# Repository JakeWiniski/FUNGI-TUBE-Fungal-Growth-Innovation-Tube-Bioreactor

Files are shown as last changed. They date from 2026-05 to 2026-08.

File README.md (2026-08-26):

# FUNGI-TUBE: Fungal-Growth-Innovation-Tube-Bioreactor


FUNGI-TUBE (Fungal Growth & Innovation Tube Bioreactor) is a modular solid-state bioreactor system that integrates passive aeration and low-cost, non-invasive sensing to monitor and optimize fungal growth and metabolism across diverse applications—including mycelium materials, mushroom cultivation, and solid-state fermentation. Designed to maximize data richness relative to unit cost, the system supports large experimental arrays (high n) with a deep feature space, enabling time-resolved insight into both physical growth and metabolic activity. By coupling structural, optical, thermal, and gas-phase monitoring, FUNGI-TUBE functions as a low-cost “budget biofoundry” for adaptive learning, trait screening, and myco-centric R&D.

## FRAME — *Fungal-Response-And-Mycelium-Evolution Module*

The **FRAME** is the core unit of the system: a 50 mL conical centrifuge tube holder modified to support **non-invasive monitoring** of growth dynamics in solid-state fermentation. This sensorized tube holder houses the fungal culture in a standard conical 50mL centrifuge tube and enables quantitative tracking of growth development over time.

Each **FRAME** module integrates:

- **Capacitance sensor**  
  Detects changes in the dielectric properties of the solid substrate, providing a proxy signal for **mycelial growth, substrate colonization, and moisture dynamics**. The capacitance sensor in the FUNGI-TUBE system provides a non-invasive, quantitative proxy for fungal growth by detecting changes in the electrical properties of the substrate. As fungal mycelium colonizes the substrate, it alters the local dielectric environment through the accumulation of biomass, extracellular matrix, and moisture redistribution. These biological and physical changes effect the overall capacitance measured by the sensor, which is positioned externally along the substrate tube. This method allows for continuous, non-invasive, and low-cost tracking of mycelial expansion. Capacitance data, when analyzed alongside other sensor outputs such as CO₂, VOCs, and temperature, offers a powerful window into both structural growth dynamics and underlying metabolic activity.

- **RGB color sensor**  
  Measures the **relative brightness, pigmentation, and density** of surface mycelium. Useful for monitoring visual colonization density, morphological transitions, and the onset of **secondary metabolite** production (e.g., pigments).

- **Temperature sensor**  
  Logs **tube surface temperature**, enabling detection of **metabolic heat generation** and aiding in the interpretation of growth phase and respiration kinetics. Additional integrated external sensors also capture environment temperature. 

These sensors are mounted externally and aligned with the body of the tube, enabling continuous data acquisition without disturbing the culture. Sensor data is logged locally (or can be transmitted via ESP-NOW), supporting high-resolution time series analysis of fungal growth evolution.

When paired with the **FOGM** (Fungal Off-Gas Monitor) module, the FUNGI-TUBE system offers a low-cost, modular platform for studying fungal physiology, growth kinetics, and environmental response in real time.

## FOGM — *Fungal Off-Gas Monitor Module*

**FOGM** is a modular sensor chamber designed to monitor the gaseous byproducts of fungal growth in small-scale, solid-state fermentation systems — specifically the 50 mL **FUNGI-TUBE** bioreactor platform.

This detachable cap integrates multiple environmental sensors to passively sample the headspace gas diffusing from the growth tube, providing real-time data on:

- **CO₂ concentration** 
- **Relative humidity (RH)**  
- **Volatile organic compounds (VOCs)**  

The FOGM chamber features a tortuous internal gas path with inlet and outlet ports that encourage mixing, prevent direct gas escape, and stabilize readings. It is designed to be 3D printable and easy to assemble.

FOGM enables detailed monitoring of fungal metabolic activity and environmental response in micro-cultivation experiments. Paired with the FRAME this allows for hollistic co-featurization of mycelium and metabolic evolution. 

## FUNGI-TUBE Shield & Firmware

The FUNGI-TUBE Shield is a purpose-built expansion board designed to support operation with the ESP32 microcontroller, providing both the core functionality and flexible optionality needed for diverse fungal cultivation and monitoring scenarios. By building on the ESP32 platform, the system gains integrated Wi-Fi and Bluetooth connectivity, opening pathways for wireless data transmission, real-time monitoring, and remote experiment management. This optional connectivity allows the same hardware to operate as a completely self-contained logger for offline experiments or as part of a networked, cloud-connected array for more complex studies. The shield itself integrates a TCA9548A I²C multiplexer for scalable sensor interfacing, 4.7kΩ pull-up resistors, an ADS1115 analog-to-digital converter, and a logic level shifter to enable robust communication across both 3.3V and 5V devices. Dedicated headers for multiple I²C peripherals (e.g., SCD41, SGP40, SHT31, TCS34725), a microSD interface for local data logging, and an onboard LED for visual signaling. 

The FUNGI-TUBE firmware powers the environmental sensing platform, coordinating data collection from multiple I²C sensors via the onboard multiplexer and logging all measurements to an SD card in timestamped CSV format. Sensors monitored include CO₂ (SCD41), VOCs (SGP40), temperature and humidity (SHT31), infrared temperature (MLX90614), RGB light (TCS34725), and capacitance (via ADS1115). The firmware uses a real-time clock (RTC) to synchronize timestamps across units, supports fault-tolerant operation with retry logic and append-only logging, and uses an LED indicator for visible status signaling during idle periods. It is designed for reliable, low-maintenance deployment and can be extended to support features such as ESP-NOW wireless communication or external control modules.

## Data Processing & Featurization Pipeline

The FUNGI-TUBE system generates multi-modal time series data capturing substrate development and metabolic activity. A standardized Python processing pipeline transforms this raw data into a curated set of biologically interpretable features.

### Core Processing:

- Time alignment and signal smoothing  
- Temperature-detrending of substrate capacitance to isolate biological signals  
- Relative change calculations for CO₂, VOCs, RH, and temperature  
- RGB color analysis for surface morphology and pigmentation tracking  
- Stabilized biological ratios and composite growth/metabolic indices  
- Gas-phase concentration and flux estimation using FOGM geometry  

### Feature Set & Applications:

The resulting features provide time-resolved, interpretable insight into:

- Substrate colonization and structural change  
- Fungal respiration, VOC output, and water loss  
- Metabolic efficiency, stress response, and growth transitions   

The pipeline is provided as a reproducible Python script and Jupyter Notebook for easy application to FUNGI-TUBE datasets.

## System Overview & Application Potential

Together, the **FUNGI-TUBE** is a low-cost, scalable, and modular platform for **deep characterization of fungal growth** in solid-state culture. This system is designed to deliver rich, time-resolved data on both **internal substrate development** and **external metabolic effluent**, enabling detailed and holistic insight into fungal behavior.

By combining:

- **Substrate capacitance (growth kinetics proxy)**
- **RGB optical sensing (surface morphology and pigmentation)**
- **Localized temperature (metabolic activity)**
- **CO₂, VOC, and RH (respiration signature)**

the system provides **multi-modal, non-invasive, and non-destructive monitoring** of fungal growth across many parallel experiments.

### Applications

- **High-throughput screening** of fungal strains, substrates, additives, or environmental conditions
- **Quantitative trait measurement** for fungal R&D and bioprocess optimization
- **Data-rich input for machine learning models**, enabling predictive and adaptive control of fungal cultivation
- **Accessible prototyping tool** for researchers, educators, and startups working in **mycelium materials**, **functional mushrooms**, or **solid-state bioprocessing**
- **Off-Line Testing (Quality assurance and anomaly detection)**, by supporting functional growth forecasting models that enable early identification of deviations in substrate or spawn lot performance
- **Deployable**, by being easily assembled inexpensively using off-the-shelf components and 3D-printed parts, making it suitable for use in academic or private labs (particularly labs with cost sensitivities), mushroom farms, or distributed networks. Each unit fits within standard bench-top incubators, allowing for temperature-controlled studies without the need for specialized equipment.

This integrated monitoring framework supports the **generation of structured, multi-dimensional datasets** that can be used to train deep learning models, identify patterns in fungal behavior, and accelerate innovation in **mycelium and mushroom technologies**. Its modularity and low cost make it ideal for both small-scale lab environments and larger, automated screening arrays.

## License

The FUNGI-TUBE project is licensed under the CERN Open Hardware License v2 – Strongly Reciprocal (CERN-OHL-S-2.0).  
You are free to use, modify, and distribute the design and derivatives, provided attribution is given and derivatives remain under the same license.

See the [LICENSE](./LICENSE) file for more information.

## AI Use Disclosure

This project was developed with assistance from generative AI and coding-agent tools. AI was used for coding, debugging, and development support; analytical design, validation, interpretation, and final decisions were performed by the author.

## Citation

If you use FUNGI-TUBE in research, teaching, or development, please cite:

Winiski, J. (2026). *FUNGI-TUBE: Fungal Growth & Innovation Tube Bioreactor* (Version 1.0.0). Zenodo. https://doi.org/10.5281/zenodo.20366746

### BibTeX

```bibtex
@software{winiski_fungi_tube_2026,
  author = {Winiski, Jake},
  title = {FUNGI-TUBE: Fungal Growth & Innovation Tube Bioreactor},
  version = {1.0.0},
  year = {2026},
  publisher = {Zenodo},
  doi = {10.5281/zenodo.20366746},
  url = {https://doi.org/10.5281/zenodo.20366746}
}

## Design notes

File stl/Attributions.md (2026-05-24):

Threading for FOGM base to 50ml centrifuge tube was adapted and modified from design
TITLE: 50mL Falcon Tube Cap
AUTHOR: nelsonhall
SOURCE: https://www.thingiverse.com/thing:5360898
LICENSE: https://creativecommons.org/licenses/by/4.0/

Leur lock adapter for FOGM and Fruiting Chamber was adapted and modified from design
TITLE: Luer lock
AUTHOR: mrAkuaku
SOURCE: https://www.thingiverse.com/thing:1161394
LICENSE: https://creativecommons.org/licenses/by/4.0/

DIN rail tabletop stand was adapted and modified from design
TITLE: DIN Rail Stand (regular & deep)
AUTHOR: philklaus
SOURCE: https://www.thingiverse.com/thing:2142055
LICENSE: https://creativecommons.org/licenses/by/4.0/

Example of 35mm DIN rail clip that is compatible with the FRAME for DIN rail mounting
(Included as example, not distributed)
TITLE: DIN Rail Spring Clip
AUTHOR: peaberry
SOURCE: https://www.thingiverse.com/thing:4856091
LICENSE: https://creativecommons.org/licenses/by-nc/4.0/

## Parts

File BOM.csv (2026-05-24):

Component Description | Quantity per FUNGI-TUBE Unit | Est. $ per Component | Est. $ per FUNGI-TUBE Unit | Reference Link
Capacitive Moisture Sensor v2.0 (EC1691075) | 1 | $ 2.60 | $ 2.60 | https://www.amazon.com/Analog-Capacitive-Soil-Moisture-Sensor/dp/B09NTTR8M9
ESP32-WROOM-32 38 pin Dev Board | 1 | $ 6.00 | $ 6.00 | https://www.amazon.com/dp/B07QCP2451?ref=ppx_yo2ov_dt_b_fed_asin_title&th=1
Adafruit TCA9548A/PCA9548A I2C Multiplexer | 1 | $ 1.10 | $ 1.10 | https://www.amazon.com/Aobao-TCA9548A-Multiplexer-Breakout-Expansion/dp/B09KY1YNM9?s=electronics
Copper Foil (Capacitive Sensor Shielding) | 1 | $ 0.10 | $ 0.10 | https://www.amazon.com/dp/B01MR5DSCM?ref_=ppx_hzsearch_conn_dt_b_fed_asin_title_1
MLX90614 IR Temp Sensor (HiLetgo) | 1 | $ 10.99 | $ 10.99 | https://www.amazon.com/HiLetgo-MLX90614ESF-Non-contact-Infrared-Temperature/dp/B071VF2RWM
TCS34725 RGB Color Sensor (Teyleten) | 1 | $ 3.33 | $ 3.33 | https://www.amazon.com/Teyleten-Robot-TCS-34725-TCS34725-Recognition/dp/B087Z3K6P5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
Logic Level Converter (TXS0108E, HiLetgo) | 1 | $ 0.75 | $ 0.75 | https://www.amazon.com/HiLetgo-Channels-Converter-Bi-Directional-3-3V-5V/dp/B07F7W91LC
Resistor - 4.7kΩ 0.1W SMD chip resistor 0603mil (I2C Pull-up) | 2 | $ 0.06 | $ 0.12 | https://www.amazon.com/dp/B08QS36KCT?ref=ppx_yo2ov_dt_b_fed_asin_title&th=1
5mm Through-Hole LED | 1 | $ 0.02 | $ 0.02 | https://www.amazon.com/Transparent-Intensity-Lighting-Electronics-Components/dp/B01AUI4VQU?s=industrial
ADS1115 Analogue-Digital Converter (HiLetgo) | 1 | $ 4.00 | $ 4.00 | https://www.amazon.com/dp/B07VPFLSMX?ref=ppx_yo2ov_dt_b_fed_asin_title
Resistor (220Ω 0.25W) | 1 | $ 0.05 | $ 0.05 | https://www.adafruit.com/product/2784
MicroSD Card Module (Adafruit ADA254) | 1 | $ 7.50 | $ 7.50 | https://www.adafruit.com/product/254
SHT31 RH Sensor | 1 | $ 4.29 | $ 4.29 | https://www.amazon.com/HiLetgo-Temperature-Humidity-Interface-GY-SHT31-D/dp/B07ZSZW92J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
SGP40 VOC Sensor (Waveshare) | 1 | $ 14.99 | $ 14.99 | https://www.waveshare.com/sgp40-voc-sensor.htm
SCD41 CO2 Sensor | 1 | $ 28.99 | $ 28.99 | https://www.amazon.com/dp/B0CDWXWCS5?ref=ppx_yo2ov_dt_b_fed_asin_title
Barrel Jack (Sparkfun 5.5mm PRT-00119 or analogous) | 1 | $ 0.22 | $ 0.22 | https://www.amazon.com/dp/B07D4BK8W4?ref=ppx_yo2ov_dt_b_fed_asin_title
10uF Ceramic Capacitor | 2 | $ 0.03 | $ 0.06 | https://www.amazon.com/BOJACK-Capacitor-Multilayer-Monolithic-Assortment/dp/B085RDTCCV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
0.1uF Ceramic Capacitor | 2 | $ 0.03 | $ 0.06 | https://www.amazon.com/BOJACK-Capacitor-Multilayer-Monolithic-Assortment/dp/B085RDTCCV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
DS3231 AT24C32 RTC Module | 1 | $ 2.60 | $ 2.60 | https://www.amazon.com/dp/B00LX3V7F0?ref=ppx_yo2ov_dt_b_fed_asin_title
Generic male headers | 7 | $ 0.05 | $ 0.35 | https://www.amazon.com/Jabinco-Breakable-Header-Connector-Arduino/dp/B0817JG3XN
Generic female headers | 7 | $ 0.05 | $ 0.35 | https://www.amazon.com/Ferwooh-Single-Straight-Connector-Spacing/dp/B0CZ6X313F
USB Rev 2.0 Compliant 28/28AWG Shielded Cable | 1 | $ 1.50 | $ 1.50 | https://www.l-com.com/usb-usb-rev-20-compliant-28-28awg-bulk-cable-100-ft-spool
Shield PCB | 1 | $ 4.50 | $ 4.50 | pcbway.com
Black PLA filament | 1 | $ 1.50 | $ 1.50 | https://www.amazon.com/OVERTURE-Filament-Consumables-Dimensional-Accuracy/dp/B07PGY2JP1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
Natural PLA filament | 1 | $ 0.50 | $ 0.50 | https://www.amazon.com/dp/B0CRGHZW76?ref=ppx_yo2ov_dt_b_fed_asin_title&th=1
Translucent PLA filament | 1 | $ 0.50 | $ 0.50 | https://www.amazon.com/ELEGOO-Filament-Translucent-Dimensional-Accuracy/dp/B0DM1WT26K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
Power Supply (DC 5v 2A, 5.5x2.1mm center positive barrel jack) | 1 | $ 3.80 | $ 3.80 | https://www.amazon.com/dp/B09W96X88K?ref=ppx_yo2ov_dt_b_fed_asin_title
Female to male 5.5x2.1mm center positive barrel jack splitter | 1 | $ 3.50 | $ 3.50 | https://www.amazon.com/Splitter-Surveillance-Adapter-Y-Cable-Security/dp/B082Y1PQ6C?s=electronics
M2 set screw | 2 | $ 0.02 | $ 0.04
M3 button head machine screw | 12 | $ 0.02 | $ 0.24
M2 button head machine screw | 2 | $ 0.02 | $ 0.04
4-pin JST connectors | 5 | $ 0.43 | $ 2.15 | https://www.amazon.com/Sets-2-5-4-Connector-200mm-Female/dp/B01DUC1S14?sp_csd=d2lkZ2V0TmFtZT1zcF9hdGY
8-pin jumper wire ribbon with female connector | 1 | $ 1.85 | $ 1.85 | https://www.amazon.com/dp/B0CW9FN5RL?ref=ppx_yo2ov_dt_b_fed_asin_title
Total |  |  | $ 108.59

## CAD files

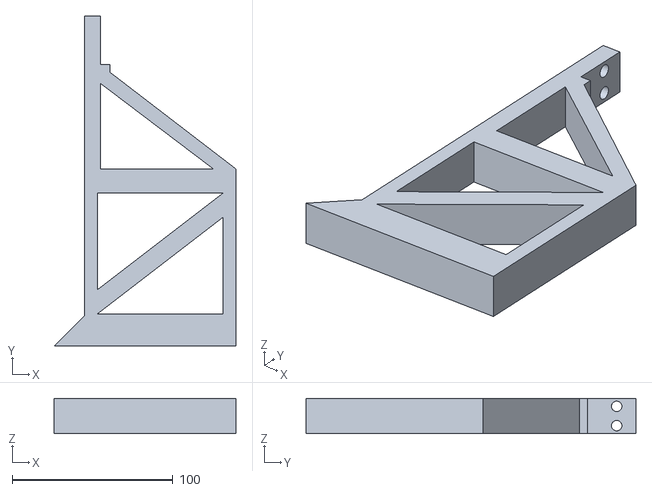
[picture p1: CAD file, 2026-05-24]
stl/DIN Rail Benchtop Stand.stl
113.0 x 205.0 x 22.0

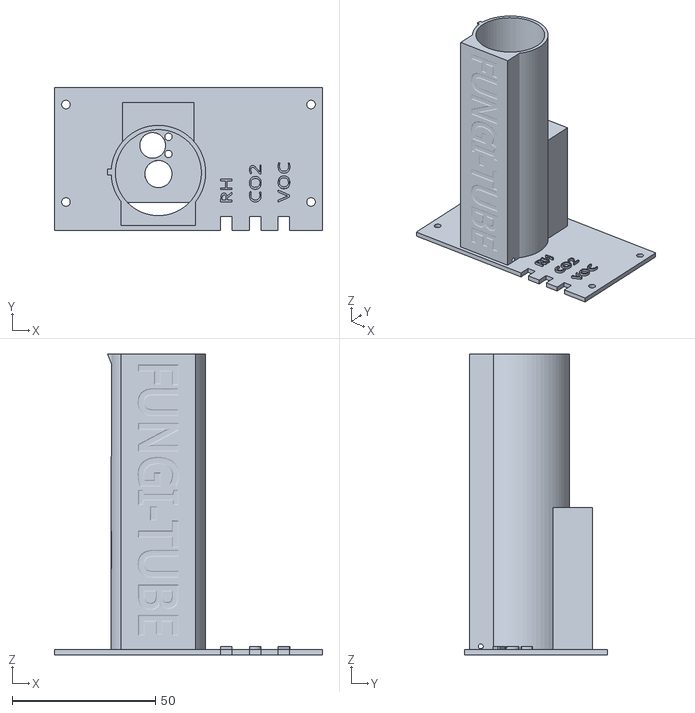
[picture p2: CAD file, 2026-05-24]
stl/FRAME Tube Housing.stl
93.5 x 50.0 x 105.0

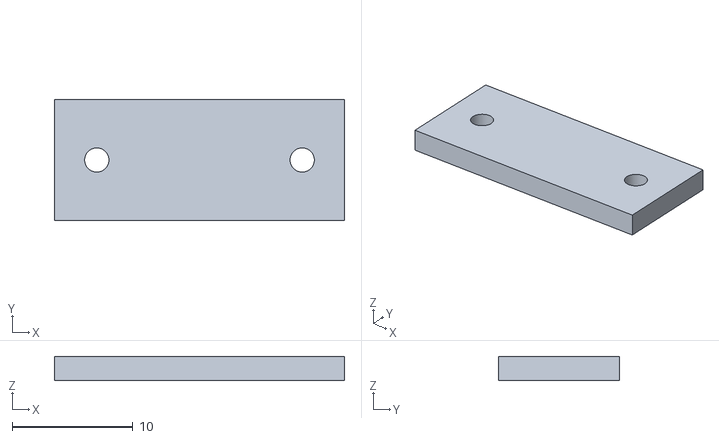
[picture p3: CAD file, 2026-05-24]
stl/FOGM CO2 Sensor Retainer.stl
24.0 x 10.0 x 2.00

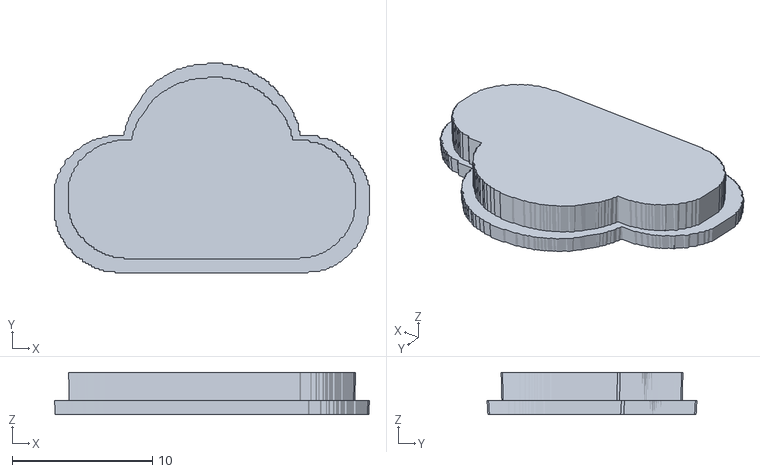
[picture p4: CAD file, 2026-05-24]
stl/Logo Cloud Plug.stl
22.5 x 15.0 x 3.00

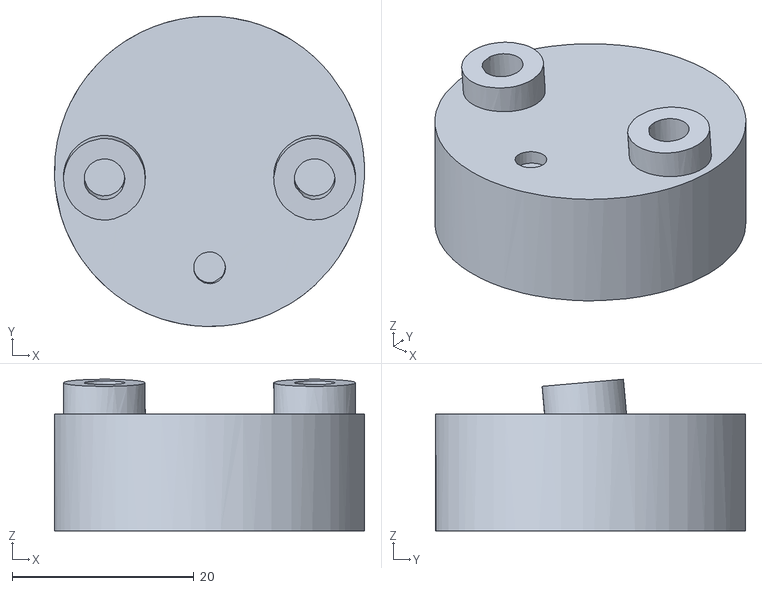
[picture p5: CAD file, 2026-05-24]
stl/FOGM Base.stl
34.1 x 34.1 x 16.7

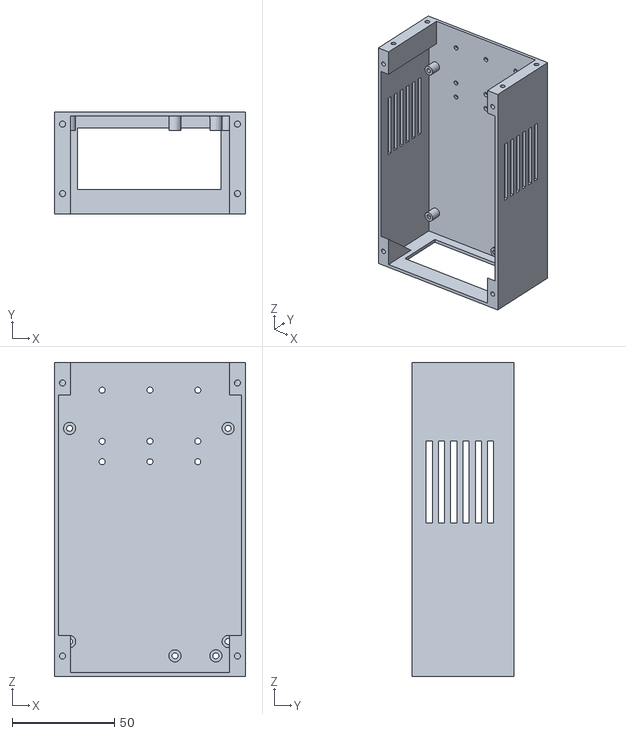
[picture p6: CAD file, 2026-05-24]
stl/FRAME Shield Housing.stl
93.5 x 50.0 x 153.5

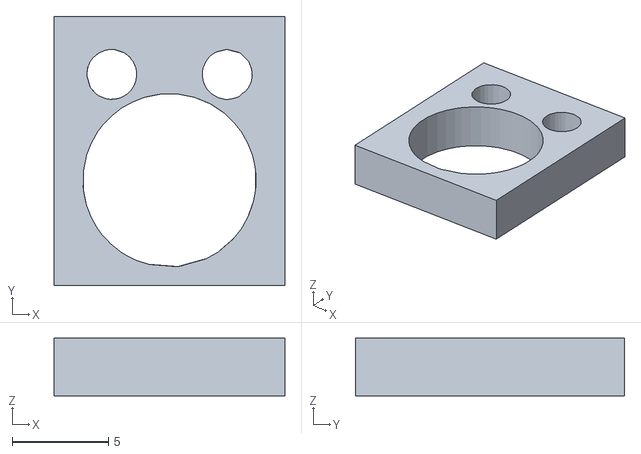
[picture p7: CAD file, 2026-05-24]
stl/FRAME IR Temp Sensor Spacer.stl
12.0 x 14.0 x 3.00

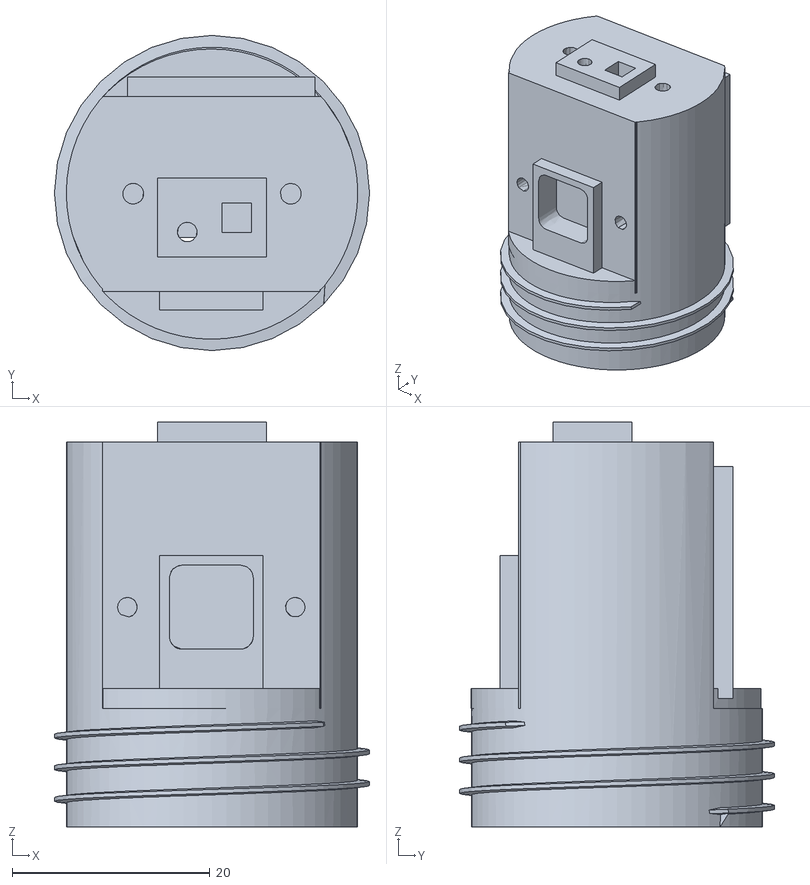
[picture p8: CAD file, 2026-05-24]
stl/FOGM Chamber for Waveshare SGP40.stl
31.9 x 31.9 x 41.0

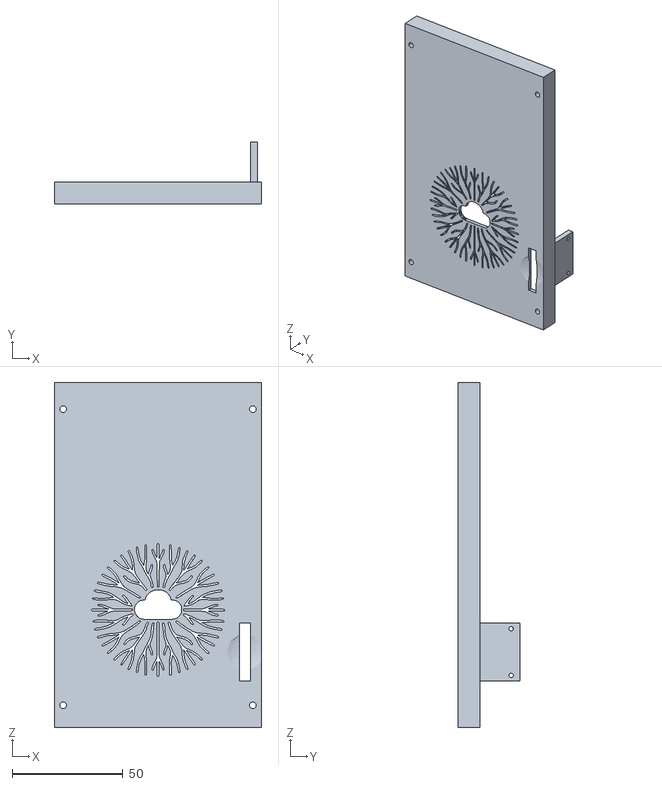
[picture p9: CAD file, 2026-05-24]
stl/FRAME Shield Housing Cover.stl
93.5 x 28.0 x 155.5

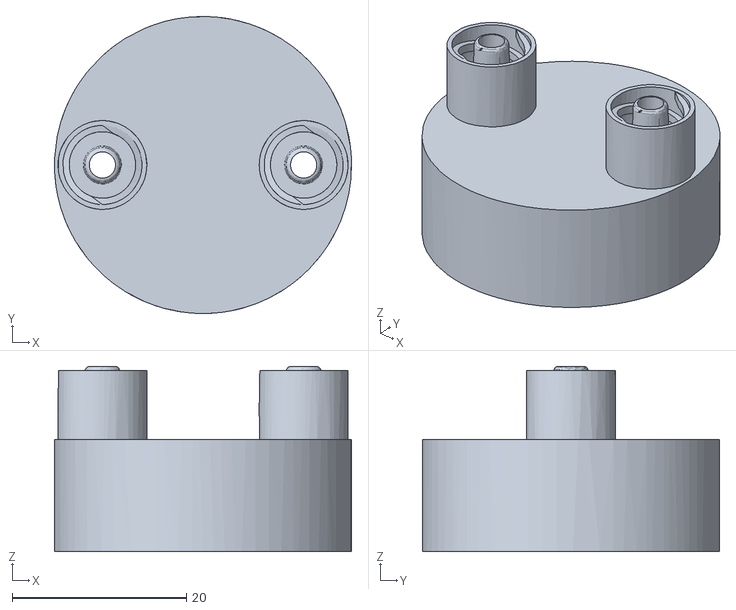
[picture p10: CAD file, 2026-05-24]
stl/Tube Cap v1.2.stl
34.1 x 34.1 x 21.3

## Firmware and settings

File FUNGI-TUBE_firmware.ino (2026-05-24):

/*
  FUNGI-TUBE Firmware v1.2
  Created by Jake Winiski
  Date: 24MAY2026
  Licensed under CERN-OHL-S v2.0
  See LICENSE file for details.
*/

#include <Wire.h>
#include "Adafruit_TCS34725.h"
#include "Adafruit_MLX90614.h"
#include "Adafruit_ADS1X15.h"
#include <SensirionI2cScd4x.h>
#include "Adafruit_SGP40.h"
#include "Adafruit_SHT31.h"
#include <SPI.h>
#include <SD.h>
#include <RTClib.h>

#define LOG_INTERVAL_MS 600000 // Logging interval in ms (recommended 10 minutes/600000 ms)
#define LED_BLINK_INTERVAL 5000 // Frequency of indicator LED blink between logging instances (recommended 5 sec/5000 ms)
#define LED_BLINK_DURATION 250 // Indicator LED on time at each blink (recommended 250 ms)
#define SCD41_WARMUP 180000 //Warmup period for SCD41 sensor (recommended 3 minutes/180000 ms)

// DS3231 RTC
RTC_DS3231 rtc;
uint32_t bootTime_epoch_s = 0;  // RTC seconds at startup

// For tracking millis() rollover
unsigned long lastMillis = 0;
uint64_t millisOffset = 0;

// SD card chip select and datafile
#define SD_CS_PIN 5
File dataFile;
bool headerChecked = false;
bool sdReady = false;

// I2C Pins
#define SDA_PIN 21
#define SCL_PIN 22

// Status LED
#define STATUS_LED_PIN 2

// I2C Multiplexer
#define PCA9548A_ADDR 0x70 
#define MUX_CH_MOISTURE 0  // Channel 0

// CO2 Sensor
#define MUX_CH_SCD41 1  // Channel 1
SensirionI2cScd4x scd41;
static int16_t error;

// RGB Sensor
#define TCS34725_INTEGRATION_TIME TCS34725_INTEGRATIONTIME_600MS
#define TCS34725_GAIN TCS34725_GAIN_16X
Adafruit_TCS34725 tcs = Adafruit_TCS34725(TCS34725_INTEGRATION_TIME, TCS34725_GAIN);

// IR Temp Sensor
Adafruit_MLX90614 mlx = Adafruit_MLX90614();

// ADS1115 for Capacitance Sensor
Adafruit_ADS1115 ads;
#define ADS_PGA_GAIN GAIN_TWOTHIRDS  // ±6.144V range, 1 bit ≈ 0.1875mV

// VOC and RH Sensors
#define MUX_CH_SGP40 2 // Channel 2
#define MUX_CH_SHT31 3 // Channel 3
Adafruit_SGP40 sgp;
Adafruit_SHT31 sht31 = Adafruit_SHT31();

// Channel Selection
void selectI2CChannel(uint8_t channel) {
  if (channel > 7) return;
  Wire.beginTransmission(PCA9548A_ADDR);
  Wire.write(1 << channel);
  Wire.endTransmission();
}

// ScanI2C function for troubleshooting
void scanI2C() {
  Serial.println("I2C scan starting...");
  for (uint8_t addr = 1; addr < 127; addr++) {
    Wire.beginTransmission(addr);
    uint8_t result = Wire.endTransmission();
    if (result == 0) {
      Serial.print("I2C device found at 0x");
      Serial.println(addr, HEX);
    }
  }
  Serial.println("Scan complete.");
}

// Data Write to SD
void logToSD(uint32_t bootTime_epoch_s, uint16_t r, uint16_t g, uint16_t b, float ambientTemp, float objectTemp, int16_t avgCapacitanceRaw,
             uint16_t co2Concentration, float co2Temp,
             uint16_t vocRaw, float vocRH, float vocTemp) {
  
  if (!sdReady) {
    Serial.println("Skipping log — SD not ready.");
    return;
  }

  unsigned long currentMillis = millis();

  // Detect millis() rollover
  if (currentMillis < lastMillis) {
    millisOffset += (uint64_t)1 << 32;  // Add 2^32 ms
  }
  lastMillis = currentMillis;

  // Compute full-time since boot
  uint64_t trueMillis = millisOffset + currentMillis;
  uint64_t currentEpochMillis = ((uint64_t)bootTime_epoch_s * 1000ULL) + trueMillis;

  // Only check for header once
  if (!headerChecked) {
    if (!SD.exists("/datalog.csv")) {
      File headerFile = SD.open("/datalog.csv", FILE_WRITE);
      if (headerFile) {
        headerFile.println("EpochMillis,R,G,B,IR_Ambient,IR_Object,CapacitanceRaw,CO2ppm,CO2Temp,VOC_Raw,VOC_RH,VOC_Temp");
        headerFile.close();
        Serial.println("Header written to SD.");
      }
    }
    headerChecked = true;
  }

  File dataFile = SD.open("/datalog.csv", FILE_APPEND);
  if (dataFile) {
    dataFile.print(currentEpochMillis); dataFile.print(",");
    dataFile.print(r); dataFile.print(",");
    dataFile.print(g); dataFile.print(",");
    dataFile.print(b); dataFile.print(",");
    dataFile.print(ambientTemp, 2); dataFile.print(",");
    dataFile.print(objectTemp, 2); dataFile.print(",");
    dataFile.print(avgCapacitanceRaw); dataFile.print(",");
    dataFile.print(co2Concentration); dataFile.print(",");
    dataFile.print(co2Temp, 2); dataFile.print(",");
    dataFile.print(vocRaw); dataFile.print(",");
    dataFile.print(vocRH, 2); dataFile.print(",");
    dataFile.println(vocTemp, 2);
    dataFile.close();
    Serial.println("Data logged to SD.");
  } else {
    Serial.println("Error opening datalog.csv");
  }
}

void setup() {
  Serial.begin(115200);
  delay(5000); // Allow ESP32 to stabilize
  Wire.begin(SDA_PIN, SCL_PIN);
  delay(5000); // Allow I2C sensors to power up before initialization
  Serial.println("I2C bus initialized.");

  scanI2C(); // For troubleshooting

  // Initialize the RTC and Save Epoch
  if (!rtc.begin()) {
    Serial.println("Couldn't find RTC");
    while (1);
  }

  if (rtc.lostPower()) {
    Serial.println("RTC lost power, setting to compile time");
    rtc.adjust(DateTime(F(__DATE__), F(__TIME__)));
  }

  DateTime now = rtc.now();
  bootTime_epoch_s = now.unixtime();  // Save epoch time at boot

  uint64_t currentEpochMillis = (uint64_t)bootTime_epoch_s * 1000ULL;
  Serial.print("FUNGI-TUBE boot EpochMillis: ");
  Serial.println(currentEpochMillis);

  // Indicator LED
  pinMode(STATUS_LED_PIN, OUTPUT);
  digitalWrite(STATUS_LED_PIN, LOW);

  // Initialize SD card with retry logic
  Serial.print("Initializing SD card...");

  for (int i = 0; i < 3; i++) {
    if (SD.begin(SD_CS_PIN)) {
      Serial.println("SD card initialized.");
      sdReady = true;
      break;
    } else {
      Serial.print("Retry "); Serial.println(i + 1);
      delay(2000);  // Wait before retrying
    }
  }

  if (!sdReady) {
    Serial.println("SD card failed after 3 attempts.");
    Serial.println("Halting: insert card and restart device.");

    // Blink indicator LED rapidly and hold indefinitely
    pinMode(STATUS_LED_PIN, OUTPUT);
    while (true) {
      digitalWrite(STATUS_LED_PIN, HIGH);
      delay(200);  // 200 ms on
      digitalWrite(STATUS_LED_PIN, LOW);
      delay(200);  // 200 ms off
    }
  }

  // Initialize TCS34725
  Serial.println("Initializing TCS34725...");
  if (tcs.begin()) {
    Serial.println("TCS34725 initialized.");
    tcs.setInterrupt(true);
  } else {
    Serial.println("TCS34725 not found!");
  }

  // Initialize MLX90614
  Serial.println("Initializing MLX90614...");
  if (mlx.begin()) {
    Serial.println("MLX90614 initialized.");
  } else {
    Serial.println("MLX90614 not found!");
  }

  // Initialize ADS1115 via multiplexer
  Serial.print("Selecting mux channel 0 for ADS1115...");
  selectI2CChannel(MUX_CH_MOISTURE);
  delay(5);
  if (ads.begin()) {
    Serial.println("ADS1115 initialized.");
    ads.setGain(ADS_PGA_GAIN); // Set gain to ±6.144V for maximum range
  } else {
    Serial.println("ADS1115 not found!");
  }

  // Initialize SCD41 on MUX Channel 1
  Serial.print("Selecting mux channel 1 for SCD41...");
  selectI2CChannel(MUX_CH_SCD41);
  delay(30);
  scd41.begin(Wire, SCD41_I2C_ADDR_62);

  error = scd41.stopPeriodicMeasurement();  // Reset just in case
  error = scd41.wakeUp();
  delay(100);
  
  // Ensure sensor is calibrated to factory default
  uint16_t frcCorrection = 0;
  error = scd41.performForcedRecalibration(0xFFFF, frcCorrection);
  if (error) {
    Serial.print("FRC error: ");
    Serial.println(error);
  } else {
    Serial.print("SCD41: Calibration offset cleared to factory default. Correction code: ");
    Serial.println(frcCorrection);
  }

  error = scd41.setAutomaticSelfCalibrationTarget(0); // Disable ASC (for faster warmup & manual control)
  error = scd41.startPeriodicMeasurement();

  Serial.println("SCD41 warming up...");
  digitalWrite(STATUS_LED_PIN, HIGH);  // Turn on LED during warmup
  delay(SCD41_WARMUP);  // Sensor warmup, set to 3 min
  digitalWrite(STATUS_LED_PIN, LOW);  // Turn off LED
  Serial.println("SCD41 initialized.");

    // Initialize SHT31 on MUX Channel 3
  Serial.print("Selecting mux channel 3 for SHT31...");
  selectI2CChannel(MUX_CH_SHT31);
  delay(5);
  if (!sht31.begin(0x44)) {  // Use 0x45 if needed
    Serial.println("SHT31 not found!");
  } else {
    Serial.println("SHT31 initialized.");
  }

  // Initialize SGP40 on MUX Channel 2
  Serial.print("Selecting mux channel 2 for SGP40...");
  selectI2CChannel(MUX_CH_SGP40);
  delay(5);
  if (!sgp.begin()) {
    Serial.println("SGP40 not found!");
  } else {
    Serial.println("SGP40 initialized.");
  }

}

void loop() {

  digitalWrite(STATUS_LED_PIN, HIGH);  // Turn on LED
  
  // RGB Sensor Read
  tcs.enable();
  delay(500);
  tcs.setInterrupt(false);  // LED on
  delay(100);

  uint16_t r, g, b, c;
  tcs.getRawData(&r, &g, &b, &c);
  tcs.setInterrupt(true);   // LED off
  delay(500);

  // IR Temp Sensor Read
  float ambientTemp = mlx.readAmbientTempC();
  float objectTemp = mlx.readObjectTempC();

  // Capacitance Sensor via ADS1115
  selectI2CChannel(MUX_CH_MOISTURE);
  delay(5);
  const int numSamples = 6; // Average multiple readings to smooth sensor noise
  int32_t sumCapacitanceRaw = 0;

  for (int i = 0; i < numSamples; i++) {
    int16_t sample = ads.readADC_SingleEnded(0);  // A0 pin
    sumCapacitanceRaw += sample;
    delay(500); 
  }

  int16_t avgCapacitanceRaw = static_cast<int16_t>(sumCapacitanceRaw / numSamples);

  // NOTE:
  // The value `avgCapacitanceRaw` represents a smoothed raw capacitance signal,
  // which reflects relative dielectric changes over time (e.g., due to fungal growth).
  // While not calibrated to absolute moisture content, it is possible to do so
  // through substrate-specific calibration. This would require determining the
  // relationship between raw ADC values and gravimetric moisture content
  // across a range of known substrate moisture levels.

  // SCD41 CO₂ Sensor Read
  selectI2CChannel(MUX_CH_SCD41);
  delay(5);
  uint16_t co2Concentration = 0;
  float co2Temp = 0.0;
  float co2RH = 0.0;

  error = scd41.readMeasurement(co2Concentration, co2Temp, co2RH);

  if (error) {
  Serial.print("SCD41 read error: ");
  Serial.println(error);
  co2Concentration = 0;
  co2Temp = 0.0;
  co2RH = 0.0; // Read but unused; reserved for future use
  }

  // VOC and RH Sensor Read
  selectI2CChannel(MUX_CH_SHT31);
  delay(5);
  float vocTemp = sht31.readTemperature();
  float vocRH = sht31.readHumidity();

  selectI2CChannel(MUX_CH_SGP40);
  delay(5);
  uint16_t vocRaw = sgp.measureRaw(vocRH, vocTemp);

  // Logs all sensor readings to SD card as CSV
  // Check if header has already been written (only once per boot)
  logToSD(bootTime_epoch_s, r, g, b, ambientTemp, objectTemp, avgCapacitanceRaw,
        co2Concentration, co2Temp,
        vocRaw, vocRH, vocTemp);
  delay(500);

  // Serial Output
  Serial.print("R: "); Serial.print(r);
  Serial.print(" G: "); Serial.print(g);
  Serial.print(" B: "); Serial.print(b);
  Serial.print(" IR Ambient Temp: "); Serial.print(ambientTemp); Serial.print("°C");
  Serial.print(" IR Object Temp: "); Serial.print(objectTemp); Serial.print("°C");
  Serial.print(" Capacitance Raw: "); Serial.print(avgCapacitanceRaw);
  Serial.print(" CO2 [ppm]: "); Serial.print(co2Concentration);
  Serial.print(" CO2 Temp: "); Serial.print(co2Temp); Serial.print("°C");
  Serial.print(" VOC Raw: "); Serial.print(vocRaw);
  Serial.print(" VOC RH: "); Serial.print(vocRH);
  Serial.print(" VOC Temp: "); Serial.println(vocTemp);

  digitalWrite(STATUS_LED_PIN, HIGH);  // Turn off LED

  //Delay with LED Blinking
  //(ESP-NOW transmission could be added here)
  const unsigned long totalDelay = LOG_INTERVAL_MS;     // Delay period
  const unsigned long blinkInterval = LED_BLINK_INTERVAL;    // Blink periodicity
  const unsigned long blinkDuration = LED_BLINK_DURATION;      // LED on time

  unsigned long startTime = millis();
  while (millis() - startTime < totalDelay) {
    unsigned long elapsed = millis() - startTime;
    if ((elapsed % blinkInterval) < blinkDuration) {
      digitalWrite(STATUS_LED_PIN, HIGH);
    } else {
      digitalWrite(STATUS_LED_PIN, LOW);
    }
    delay(10); // Keeps the loop responsive
  }
  digitalWrite(STATUS_LED_PIN, LOW);  // Ensure LED is off
}

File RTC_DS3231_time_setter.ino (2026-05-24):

#include <Wire.h>
#include "RTClib.h"

RTC_DS3231 rtc;

void setup() {
  Serial.begin(115200);
  delay(1000);
  Wire.begin();

  Serial.println("Initializing RTC...");
  if (!rtc.begin()) {
    Serial.println("Couldn't find RTC. Check wiring.");
    while (1);
  }

  // Set RTC to the date & time this sketch was compiled
  rtc.adjust(DateTime(F(__DATE__), F(__TIME__)));

  Serial.println("RTC time has been set to compile time.");
  delay(1000);

  // Print confirmation
  DateTime now = rtc.now();
  Serial.print("RTC is now set to: ");
  Serial.print(now.year(), DEC);
  Serial.print('/');
  Serial.print(now.month(), DEC);
  Serial.print('/');
  Serial.print(now.day(), DEC);
  Serial.print(" ");
  Serial.print(now.hour(), DEC);
  Serial.print(':');
  Serial.print(now.minute(), DEC);
  Serial.print(':');
  Serial.println(now.second(), DEC);
}

void loop() {
  // Do nothing
}
